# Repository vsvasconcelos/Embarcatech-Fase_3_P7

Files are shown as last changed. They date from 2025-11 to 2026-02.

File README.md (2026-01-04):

# Robô Seguidor de faixa colorida com módulo de Visão Computacional inteligente
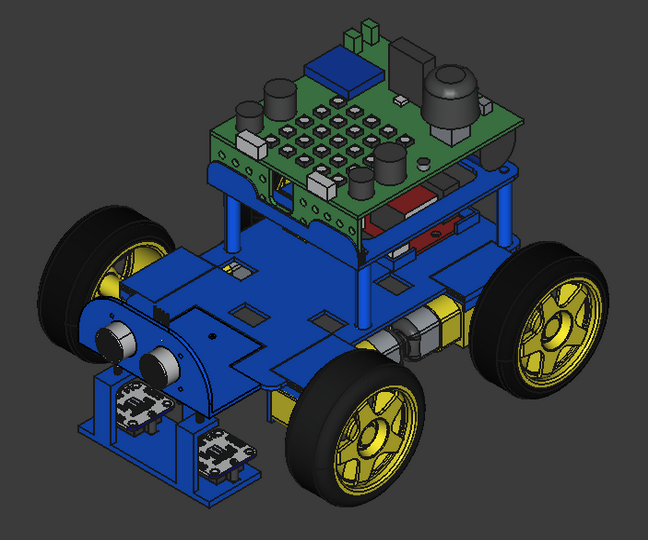
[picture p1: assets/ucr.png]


---
## Equipe:   
### Desenvolvimento: 
- [Luan Felipe Azzi](https://www.linkedin.com/in/luan-azzi/) - Robô Móvel (UCR)
- [Vagner Sanches Vasconcelos](https://www.linkedin.com/in/vsvasconcelos/) - Visão Computacional (UPV)
### Orientação:
- [Vinicius Ares](https://www.linkedin.com/in/viniciusares/)
### Coordenação:
- [Prof. Dr. Fabiano Fruett](https://www.linkedin.com/in/fabiano-fruett-816008245/)

---
## :wrench: Conteúdo   
| Pasta | Descrição |
|---|---|
| etapa_1 |Conhecendo o cliente e arquitetura do sistema |
| etapa_2 |Desenvolvimento e integração parcial dos módulos |
| etapa_3 |Testes e otimização dos sistemas |
| etapa_4 |Validação e documentação técnica final |
| etapa_5 |Entrega final |
---
## :dart: Objetivo do projeto
O objetivo geral do projeto é elevar o nível de maturidade tecnológica (TRL) de um robô móvel que, além de se locomover, será capaz de seguir diferentes cores e desviar de obstáculos no trajeto. Também é escopo um módulo de Visão Computacional inteligente que, acoplado ao robô, ampliará suas habilidades e permitirá ainda a incorporação de estratégias de controle com base em IA ao robô.

---
## Módulos   
O projeto possui dois módulos:    
- Unidade de Controle do Robô - UCR (BitDogLab - MPU Pi Pico W);     
- Unidade de Processamento de Visão - UPV (SBC - Pi Zero 2 W).     
A comunicação entre eles ocorre por meio de BLE (Bluetooth Low Energy).    
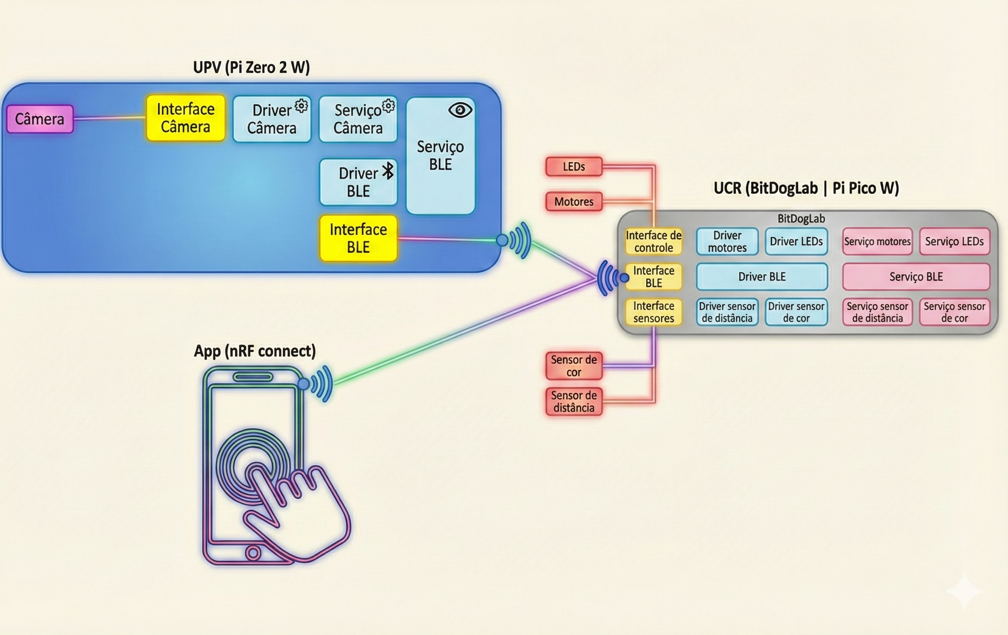
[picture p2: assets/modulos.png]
Modulos


---
### Unidade de Controle do Robô
Este projeto implementa um robô autônomo que:
- **Segue linhas coloridas** com prioridade: 🟡 Amarelo > 🔴 Vermelho > 🔵 Azul
- **Para quando detecta preto** (linha de parada)
- **Evita obstáculos** usando sensor ultrassônico
- **Indica status** através de LED RGB

#### Hardware Necessário

| Componente | Quantidade | Descrição |
|---|:---:|---|
| BitDogLab | 1 | Microcontrolador principal |
| TCS34725 | 2 | Sensor de cor I2C (esquerdo/direito) |
| SR04 (módulo I2C) | 1 | Sensor ultrassônico para obstáculos |
| BitMovel | 1 | Driver de motor |
| Motor DC | 2 | Motores para as rodas |
| LED RGB | 1 | Indicador de status |
| Botão | 1 | Start/Stop |

#### A arquitetura de software
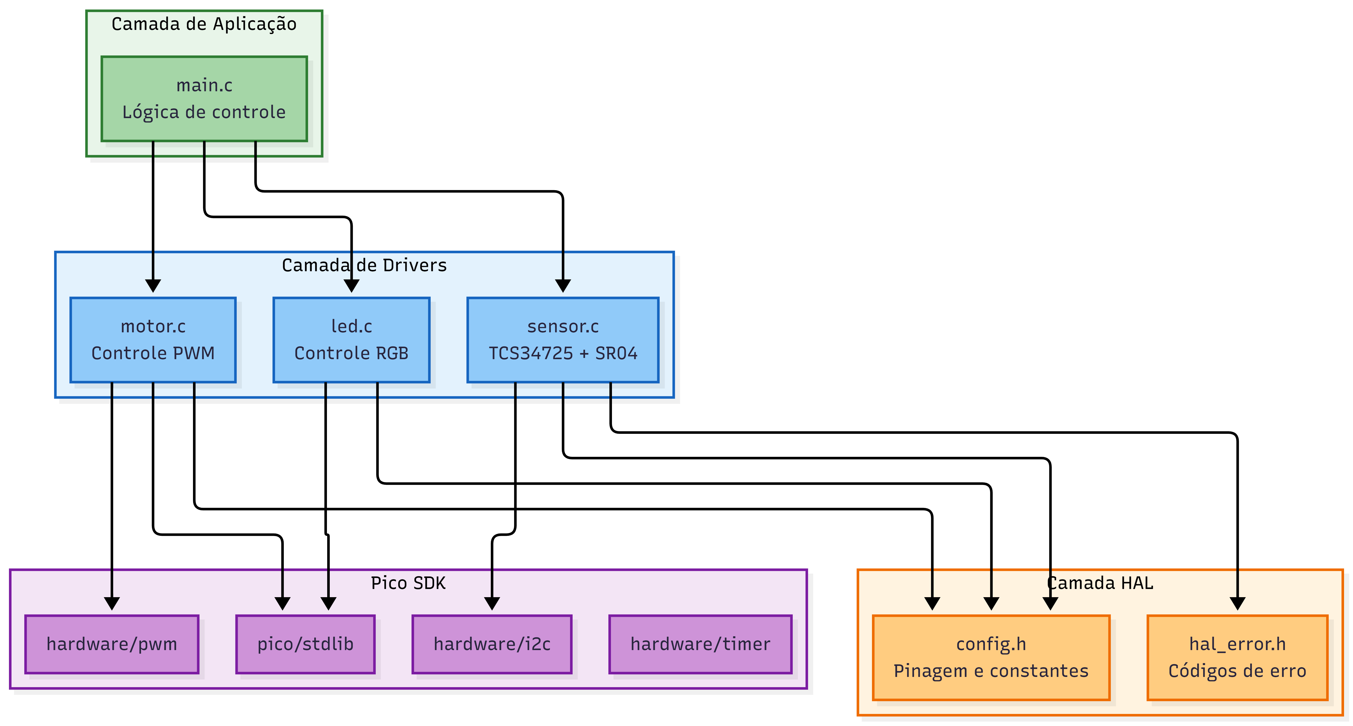
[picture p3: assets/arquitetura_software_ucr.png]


#### Fluxograma de software    
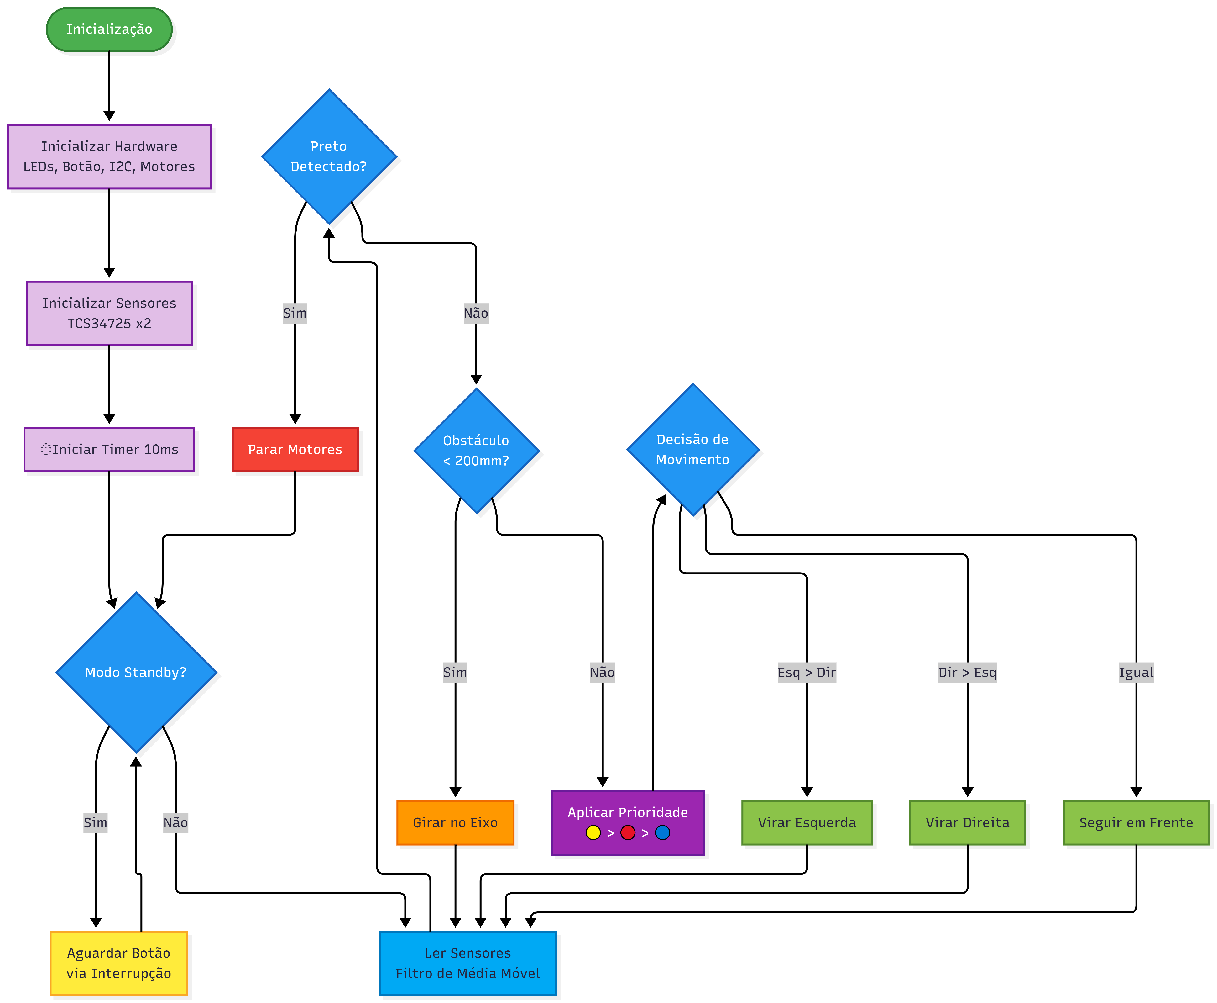
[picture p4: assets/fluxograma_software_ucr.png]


---
### Unidade de Processamento de Visão  
A UPV utiliza a SBC Pi Zero 2W com câmera de 5 MP.    
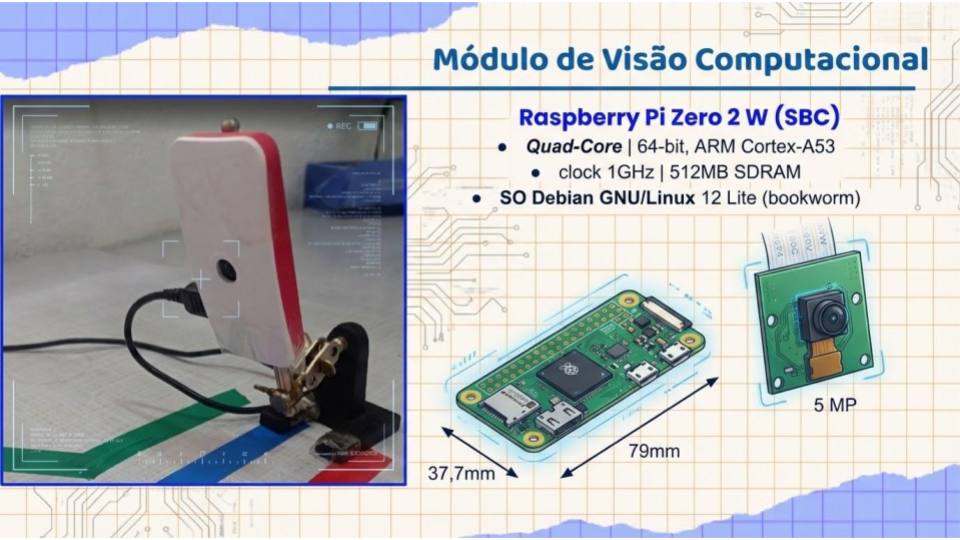
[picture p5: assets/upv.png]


#### A arquitetura de software
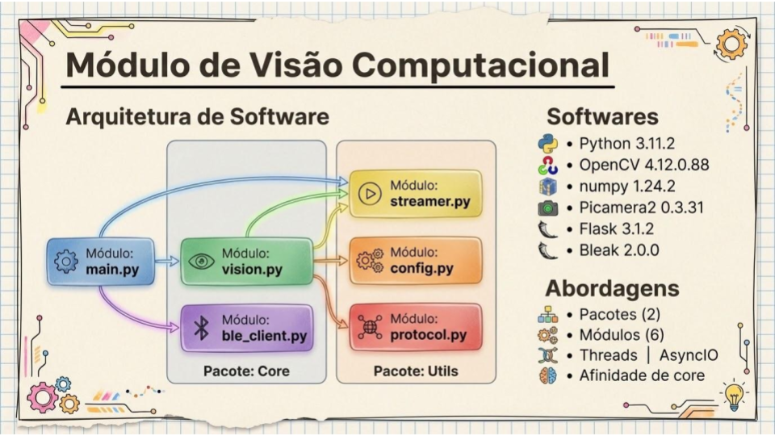
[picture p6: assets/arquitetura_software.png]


#### Diagrama de arquitetura e fluxos    
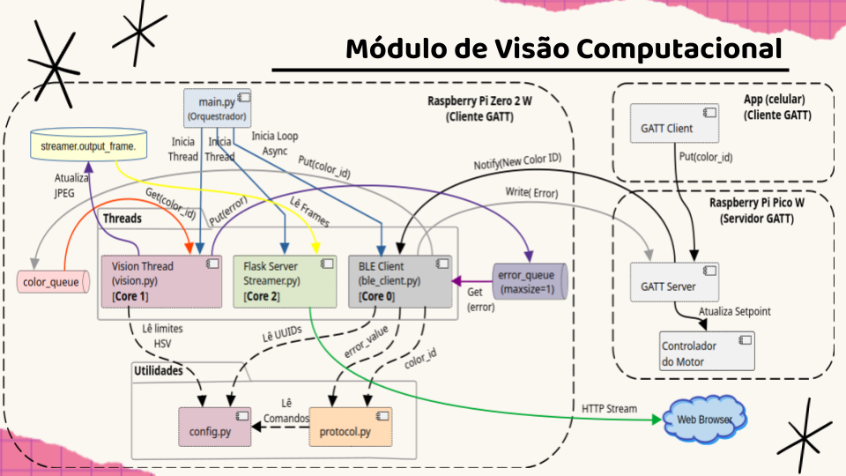
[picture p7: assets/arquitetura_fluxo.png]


## :floppy_disk: Como compilar e executar o código    
---
1. Abra o projeto no VS Code, usando o ambiente com suporte ao SDK do Raspberry Pi Pico (CMake + compilador ARM);
2. Compile o projeto normalmente (Ctrl+Shift+B no VS Code ou via terminal com cmake e make);
3. Conecte sua BitDogLab via cabo USB e coloque a Pico no modo de boot (pressione o botão BOOTSEL e conecte o cabo);
4. Copie o arquivo .uf2 gerado para a unidade de armazenamento que aparece (RPI-RP2);
5. A Pico reiniciará automaticamente e começará a executar o código.

---
## :movie_camera: Imagens e/ou vídeos do projeto em funcionamento    

### Unidade de Controle do Robô

UCR (https://youtu.be/0dy9BSEWP0k "UCR")

### Unidade de Processamento de Visão   
UPV - PiZero2W (https://youtu.be/BHwsimsb04M "UPV") 

---
## :chart_with_upwards_trend: Resultados esperados ou obtidos     

### Unidade de Controle do Robô

A UCR foi capaz de seguir as linhas coloridas individualmente (🟡 Amarelo, 🔴 Vermelho, 🔵 Azul), parar quando detectou preto (linha de parada) e evitar obstáculos usando sensor ultrassônico. O LED RGB indicava o status do robô.

---
## Referências:
-
-

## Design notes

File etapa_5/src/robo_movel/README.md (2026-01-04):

# Robô Seguidor de Linha por Cor

Projeto de robô móvel seguidor de linha que identifica e segue linhas coloridas com sistema de prioridade, desenvolvido para a **BitDogLab**.

## Descrição

Este projeto implementa um robô autônomo que:
- **Segue linhas coloridas** com prioridade: 🟡 Amarelo > 🔴 Vermelho > 🔵 Azul
- **Para quando detecta preto** (linha de parada)
- **Evita obstáculos** usando sensor ultrassônico
- **Indica status** através de LED RGB

## Hardware Necessário

| Componente | Quantidade | Descrição |
|---|:---:|---|
| BitDogLab | 1 | Microcontrolador principal |
| TCS34725 | 2 | Sensor de cor I2C (esquerdo/direito) |
| SR04 (módulo I2C) | 1 | Sensor ultrassônico para obstáculos |
| BitMovel | 1 | Driver de motor |
| Motor DC | 2 | Motores para as rodas |
| LED RGB | 1 | Indicador de status |
| Botão | 1 | Start/Stop |

## Pinagem

### I2C
| Bus | Função | SDA | SCL |
|-----|---|:---:|:---:|
| I2C0 | Sensor de cor esquerdo | GP0 | GP1 |
| I2C1 | Sensor de cor direito + Ultrassônico | GP2 | GP3 |

### Motores
| Motor | Forward | Backward | PWM |
|---|:---:|:---:|:---:|
| Esquerdo | GP9 | GP4 | GP8 |
| Direito | GP18 | GP19 | GP16 |
| Standby | GP20 | - | - |

### LED RGB
| Cor | Pino |
|-----|:----:|
| Verde | GP11 |
| Azul | GP12 |
| Vermelho | GP13 |

### Botão
- **Start/Stop**: GP5

## Como Usar

1. **Ligue o robô** - LEDs acendem indicando modo de espera
2. **Pressione o botão** (GP5) para iniciar
3. O robô começará a seguir as linhas coloridas
4. **Para parar**: coloque o robô sobre uma superfície preta

### Indicadores LED

| Cor LED | Significado |
|---|---|
| 🔴🟢🔵 (Branco) | Modo de espera |
| 🟢 Verde | Seguindo linha |
| 🔵 Azul | Evitando obstáculo |
| 🔴🔵 Magenta | Parada (preto detectado) |

## Estrutura do Projeto

```
robo_movel/
├── main.c          # Aplicação principal e lógica de controle
├── config.h        # Configurações de hardware e constantes
├── led.c/h         # Controle do LED RGB
├── motor.c/h       # Controle dos motores DC
├── sensor.c/h      # Leitura dos sensores (cor e ultrassônico)
├── CMakeLists.txt  # Configuração de build
└── README.md       # Este arquivo
```

## Configurações Ajustáveis

No arquivo `config.h`, você pode ajustar:

```c
#define MOTOR_BASE_SPEED      17000   // Velocidade base (PWM)
#define MOTOR_SPIN_SPEED      15000   // Velocidade de curva
#define MOTOR_TURN_TIME_MS    650     // Tempo de curva 90°
#define COLOR_BLACK_THRESHOLD 40      // Sensibilidade para preto
#define OBSTACLE_DISTANCE_MM  200     // Distância de obstáculo (mm)
#define COLOR_LOCK_TIME_MS    500     // Tempo de lock de prioridade
```

## Sistema de Prioridade de Cores

O robô usa um sistema inteligente para decidir qual linha seguir quando detecta múltiplas cores:

1. **Amarelo** (prioridade máxima) - Sempre seguido
2. **Vermelho** (prioridade média) - Seguido se não houver amarelo
3. **Azul** (prioridade baixa) - Seguido se não houver vermelho ou amarelo
4. **Preto** (especial) - Causa parada imediata

## Licença

Projeto desenvolvido para fins educacionais no programa **Embarcatech**.

---

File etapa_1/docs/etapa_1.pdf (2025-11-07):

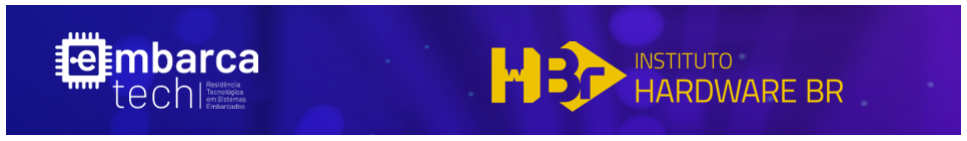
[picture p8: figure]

# Relatório de Projeto Residência Tecnológica em Sistemas Embarcados - Embarcatech

### Projeto: Robô Seguidor de Cor

Robô Seguidor de Cor com módulo de Visão Computacional inteligente

### Residentes: Luan Felipe Azzi Vagner Sanches Vasconcelos Vinícius Esperança Mantovani

### Outubro de 2025

## Histórico de Revisões

Data | Versão | Descrição
12/10/2025 | 1.0 | Semana 1 - Conhecendo o cliente e o problema
19/10/2025 | 2.0 | Semana 2 - Arquitetura e especificações
26/10/2025 | 3.0 | Semana 3 - Escolha de Hardware e Planejamento para mudanças

## Conteúdo

1 Objetivo do documento | 4
2 Conhecer o cliente e definir o problema. | 4
2.1 Canvas da proposta de valor | 4
2.2 Contexto de negócio | 7
2.3 Objetivo geral | 7
2.4 Contexto do sistema | 7
2.5 Requisitos Iniciais | 9
2.6 Avaliação do TRL atual e avanços esperados | 12
3 Arquitetura e especificações técnicas (Etapa 1 - Semana 2) | 13
3.1 Requisitos associados às camadas do sistema | 14
3.2 Diagrama de blocos | 17
3.3 Diagramas de camadas e interfaces entre módulos | 20

### 4 Escolha de Hardware e Planejamento para Mudanças (Etapa 1 - Semana 3) 21

4.1 Matriz comparativa de hardware | 21
4.2 Justificativas das escolhas | 23
4.3 Plano de abstração de hardware (HAL) | 24
4.4 Análise de Riscos | 26
4.5 Diagrama consolidado do sistema completo | 27
5 Referências | 27

# 1 Objetivo do documento

Este relatório documenta de forma sistemática todas as atividades desenvolvidas no âmbito do projeto até a data atual. Informações adicionais e novos resultados serão incorporados em versões subsequentes deste documento, conforme o progresso do trabalho.
2 Conhecer o cliente e definir o problema.

Esta seção apresenta o contexto de negócio no qual se insere o projeto 'Robô seguidor de cor com módulo de visão computacional inteligente', abrangendo seu objetivo geral, a caracterização do problema, as principais tarefas envolvidas na solução proposta, bem como os desafios e oportunidades previstos ao longo do desenvolvimento.

## 2.1 Canvas da proposta de valor

Para compreender quem é o cliente e qual problema o projeto deverá resolver, bem como identificar o valor agregado pela solução e o ambiente em que ela será utilizada, foi utilizado a ferramenta Canvas da Proposta de Valor proposta por [1] e sintetizada na Fig. 1.

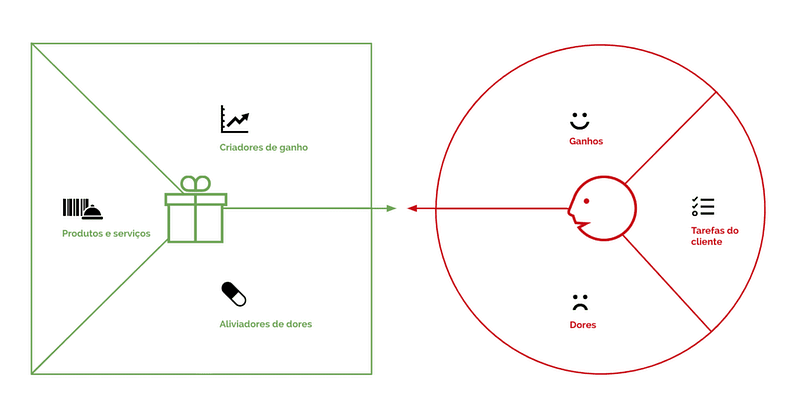
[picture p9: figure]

Figura 1 – Canvas da Proposta de Valor Fonte: [1] (https://www.zotero.org/google-docs/?iki5DS)

O Mapa do Cliente - lado direito do Canvas -, é utilizado para compreender profundamente o cliente. Seu propósito é identificar quem é o cliente, quais problemas o projeto deve resolver, o valor agregado pela solução e o ambiente em que será utilizado. Já na parte da esquerda, tem-se o Mapa de Valor, utilizado para identificar o valor agregado pela solução e o ambiente em que ela será utilizada.
Quando ambos os mapas convergem, isso é chamado de Encaixe da Proposta de Valor (Value Proposition Fit), e isso ocorre quando a proposta de valor de uma empresa atende de forma eficaz às necessidades, dores e ganhos do cliente.

### 2.1.1 Mapa do Cliente

O cenário de uso ocorre em contextos educacionais.

2.1.1.1 Tarefas do Cliente
1. Tarefas Funcionais: Capacitação de estudantes; pesquisa e desenvolvimento de estratégias de controle do robô; reputação e prestígio da instituição de ensino nas competições de robótica.
2. Tarefas Sociais: Socialização; mobilidade social.
3. Tarefas Emocionais: Aprendizagem socioemocional (soft-skills).

2.1.1.2 Dores
Investimento inicial (CAPEX) nos robôs.
1. Custos de manutenção e reposição dos robôs.
2. Falta de força de trabalho especializada em sistemas embarcados na instituição.
3. Dificuldades com o diagnóstico de falhas nos kits.
4. Falta de padronização das provas, exigindo adaptações constantes dos robôs.
5. Falta de integração curricular.
6. Trade-Off entre a gestão de resultados e o processo de aprendizagem.

2.1.1.3 Ganhos
1. Pedagógicos e de aprendizagem, com a aplicação prática de teorias abstratas como: matemática; física; programação e lógica; e o estímulo ao pensamento computacional.
2. Aprendizagem baseada em projetos (PBL).
3. Desenvolvimento da cultura maker.

4. Desenvolvimento de atitudes socioemocionais (soft skills): trabalho em equipe; colaboração; resiliência; gestão da frustração; criatividade; resolução de problemas; gestão de projetos; comunicação técnica; entre outras.
5. Ganhos de marketing e visibilidade institucional.
6. Motivação e engajamento dos alunos; capacitação e valorização dos professores; fortalecimento do sentimento de pertencimento; preparação para o mercado de trabalho.

### 2.1.2 Mapa de Valor

O protótipo do robô seguidor de cor com módulo de visão computacional inteligente será aplicável a atividades didáticas, feiras de ciência e oficinas de robótica educacional.

2.1.2.1 Aliviadores de dores
1. Robô básico com custo similar a média de mercado.
2. Robô com elevado tempo médio entre falhas (MTBF) e peças de reposição de baixo custo.
3. Sistema de diagnóstico de falhas embarcado.
4. Módulo de visão computacional (opcional), que permite adaptações automáticas para todos os tipos de provas, e ainda a implementação de novas modalidades de controle para o robô, incluindo modelos de inteligência artificial.

2.1.2.2 Criadores de ganhos
1. Robô programável, em linguagens de alto nível e Low/No-Code, permitindo a aplicação prática de: matemática; física; programação e lógica, bem como, a aplicação de IA, com o módulo opcional de visão computacional.
2. Aplicação plena da abordagem pedagógica do PBL e da cultura maker.
3. Desenvolvimento amplo de capacidades multidisciplinares de hard e soft-skill.
4. Aumento das chances de ganhos de marketing e visibilidade institucional, principalmente com o robô embarcado com visão computacional.

5. Preparação dos alunos para o mercado de trabalho e para a vida (soft-skill).

2.1.2.3 Produtos e serviços
1. Robô móvel, sem fio e com 4 rodas, capaz de seguir faixas de cores e desviar de obstáculos de forma autônoma. Em sua versão básica, as habilidades de seguir a faixa e desviar de obstáculos ocorrem por meio de sensores de cor e distância (TOF/Ultrassônico).
2. Módulo opcional de visão computacional, que amplia as habilidades do robô, habilitando-o para competições em trilhas mais desafiadoras. Este módulo é acoplado facilmente a versão básica do robô, e também permite a incorporação de novas estratégias de controle, inclusive com técnicas de Inteligência Artificial.

## 2.2 Contexto de negócio

O mercado de robótica educacional no Brasil vive um momento de expansão acelerada, impulsionado principalmente pela implementação da Base Nacional Comum Curricular (BNCC), que incorporou o pensamento computacional como competência obrigatória, e ainda pela crescente conscientização sobre a importância das habilidades STEM (Ciência, Tecnologia, Engenharia e Matemática). Este marco regulatório abriu um mercado potencial de milhões de estudantes nas redes pública e privada.
Conforme [2], esse mercado terá um crescimento exponencial, chegando a US$135 milhões até 2035, o que representa um crescimento de 300% em relação a 2023.

## 2.3 Objetivo geral

O objetivo geral do projeto é elevar o nível de maturidade tecnológica (TRL) de um robô móvel que, além de se locomover, será capaz de seguir diferentes cores e desviar de obstáculos no trajeto. Também é escopo um módulo de Visão Computacional inteligente que, acoplado ao robô, ampliará suas habilidades e permitirá ainda a incorporação de estratégias de controle com base em IA ao robô.

## 2.4 Contexto do sistema

A seguir, é apresentado um diagrama de contexto do sistema. Por meio dele, é possível identificar as interações do robô com os fatores externos que atuam sobre seu funcionamento. Nesse diagrama, pode-se notar a relação do robô com obstáculos, que o fazem parar e aguardar até sua retirada, a relação com uma faixa de cor específica, a qual ele deve seguir e, a relação com o usuário, que determina o destino do robô (determinando, por consequência a cor a ser seguida) e recebe confirmações e outras informações do robô.

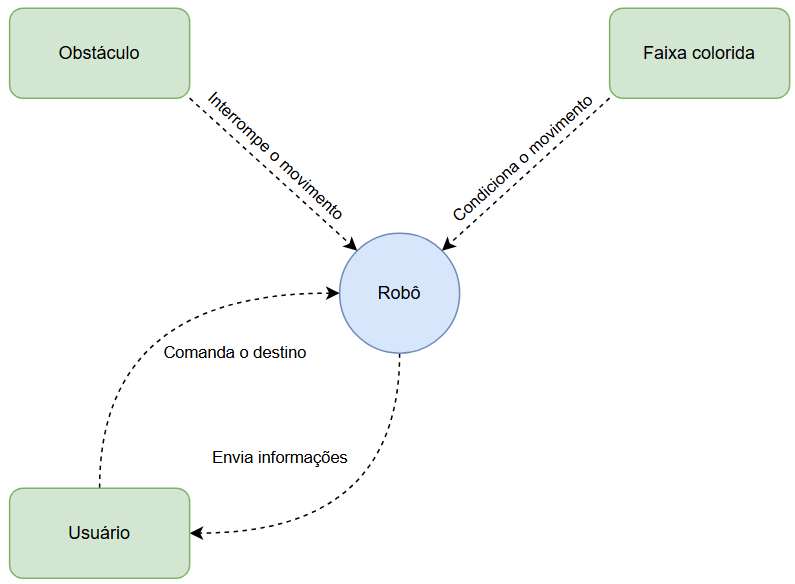
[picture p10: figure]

Figura 2 – Diagrama de Contexto do Sistema

Adicionalmente, tem-se um segundo diagrama, explicando as relações do Robô com fatores externos no caso de uso do módulo de visão computacional opcional. Nesse caso, o robô recebe comandos de controle do módulo, como forma de aumentar a precisão de seus movimentos majoritariamente na função de seguir cor.

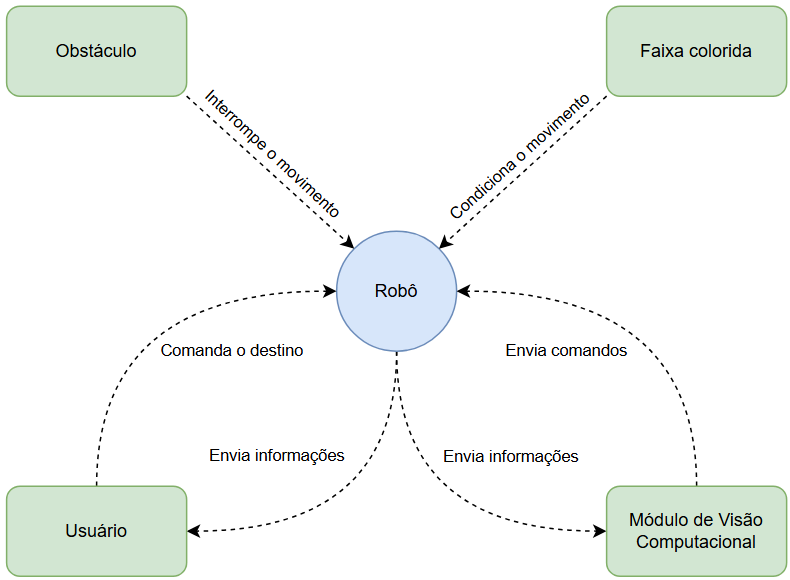
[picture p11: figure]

Figura 3 – Diagrama de Contexto do Sistema com Módulo de Visão Computacional

## 2.5 Requisitos Iniciais

A seguir, encontra-se a tabela de requisitos iniciais a ser seguida para o desenvolvimento do projeto.

ID | Tipo | Descrição breve | Prior | Critério de Aceitação
FR - 01 | Func | Movimentar-se | 1 | O robô é capaz de se mover para frente e para trás em linha reta, fazer curvas e girar para ambos os lados
FR - 02 | Func | Seguir linha | 2 | O robô é capaz de seguir uma linha
FR - 03 | Func | Distinguir linhas de diferentes cores | 3 | O robô distingue a cor de diferentes linhas e segue aquela de cor correta
FR - 04 | Func | Interromper o movimento na presença de obstáculo | 2 | O robô interrompe seu movimento caso exista um obstáculo em seu caminho, até que esse seja retirado
FR - 05 | Func | Aceitar comandos de destino remotos | 4 | O robô recebe e interpreta comandos remotos indicando a cor a ser seguida e a segue
FR - 06 | Func | Buscar a linha | 4 | Caso se perca da linha que

| | perdida | | seguia, o robô procura reencontrá-la. Caso a encontre, segue no primeiro sentido que encontrar. Caso contrário, fica parado
FR - 07 | Func | Executar comandos do módulo de visão computacional | 5 | Caso um módulo de visão seja detectado, o robô se torna um receptor de comandos, que atua sob demandas da Micro Processing Unity (MPU) controladora do sistema de visão
FR-08 | Func | Otimização de Energia | 1 | Otimização do consumo de energia para operação contínua do robô
FR-09 | Func | Adaptação do chassi existente | 5 | Caso necessário, adaptar e chassi de 4 rodas existente para melhorar a performance do robô
FR-10 | Func | Módulo de visão computacional

1
Sistema opcional à versão básica do robô, capaz de ampliar as suas capacidades originais de seguir faixas e desviar de obstáculos, permitindo
adaptações automáticas para todos os tipos de provas, e ainda a implementação de novas
modalidades de controle para o robô.

Deve ser implementado em outro microcontrolador (MPU) e
interagir com a BitDogLab para que esta realize o controle dos movimentos do robô.

Pode utilizar visão computacional clássica e/ou moderna (redes neurais).

| | | | Deve possuir dimensões físicas que não impactem substancialmente a performance do chassi atual do robô.
NFR - 01 | Não Func | Movimentar-se | 1 | O robô usa seus atuadores para movimentar suas rodas de modo a garantir que ele possa seguir em linha reta, fazer curvas e girar no próprio eixo
NFR - 02 | Não Func | Detectar uma linha e seguí-la | 2 | O robô usa seus sensores de cor para detectar a existência da linha de cor diferente da cor de fundo (branca branca por padrão) e segue por ela, verificando periódicamente para que direção deve seguir para acompanhá-la
NFR - 03 | Não Func | Escolher qual cor deve seguir | 3 | O robô verifica a presença de linha de cor específica por meio de seus sensores de cor e, caso a encontre, segue em sua direção.
NFR - 04 | Não Func | Interromper o movimento no caso de detectar uma superfície a sua frente | 2 | O robô detecta um obstáculo utilizando um sensor ultrassônico que o envia informações e distância periódicamente. No momento em que a distância for menor que um threshold determinado, o robô para de se mover até detectar um aumento dessa distância
NFR - 05 | Não Func | Receber e atender a comandos de destino remotos (via bluetooth, wifi ou outro meio de comunicação) | 4 | O robô recebe um comando que o indica a cor a ser seguida, processa esse comando e busca por essa cor entre os dados atuais de seus sensores de cor. Caso a encontre, envia uma confirmação para o aparelho controlador e segue na direção da linha de cor comandada
NFR - 06 | Não Func | Buscar pela linha perdida girando em seu eixo | 4 | Ao identificar que em nenhum de seus sensores a cor que seguia é detectada, o robô gira em seu próprio eixo até encontrá-la em um de seus sensores e, caso a

| | | | encontre, segue no sentido em que a encontrou. Caso contrário, mantém-se parado até intervenção externa
NFR - 07 | Não Func | Executar comandos do módulo de visão computacional | 5 | Quando em conexão com um módulo de visão computacional, o robô atua como um receptor de comandos e condiciona seu movimento ao controle da MPU controladora. Podendo ignorar os demais sensores que possui ou tratá-los em conjunto com as informações advindas da MPU
NFR - 08 | Não Func | Custo | 1 | Robô básico com custo similar a média de mercado e peças de reposição de baixo custo
NFR - 09 | Não Func | Robustez | 1 | Robô com elevado tempo médio entre falhas (MTBF)

Tabela 1 – Requisitos Funcionais e Não Funcionais do robô Fonte:

## 2.6 Avaliação do TRL atual e avanços esperados

Atualmente, já escolhemos os componentes e conhecemos os requisitos iniciais, tendo também a plataforma base pronta (chassi de 4 rodas radiocontrolado), conforme figura 4. No entanto, a integração dos sensores de distância e cor e da câmera para realizar uma navegação autônoma existe apenas conceitualmente, sem uma prova da viabilidade prática. Por isso, avalia-se o TRL atual como 2 - Conceito da tecnologia formulado.
Espera-se que, ao fim do período estipulado para realização do projeto, o TRL seja 4 - Validação de componente e arranjo em ambiente de laboratório, posto que temos como principal objetivo ter um protótipo funcional que execute bem as tarefas de seguir cor e desviar de obstáculos em um circuito de testes em salas de aula e feiras de ciência. Para isso, o primeiro passo é ter uma Prova de Conceito (TRL 3), integrando os sensores ao chassi e desenvolvendo um código inicial que prove que é possível ler os dados de cor e distância e, a partir disso, controlar o carrinho.

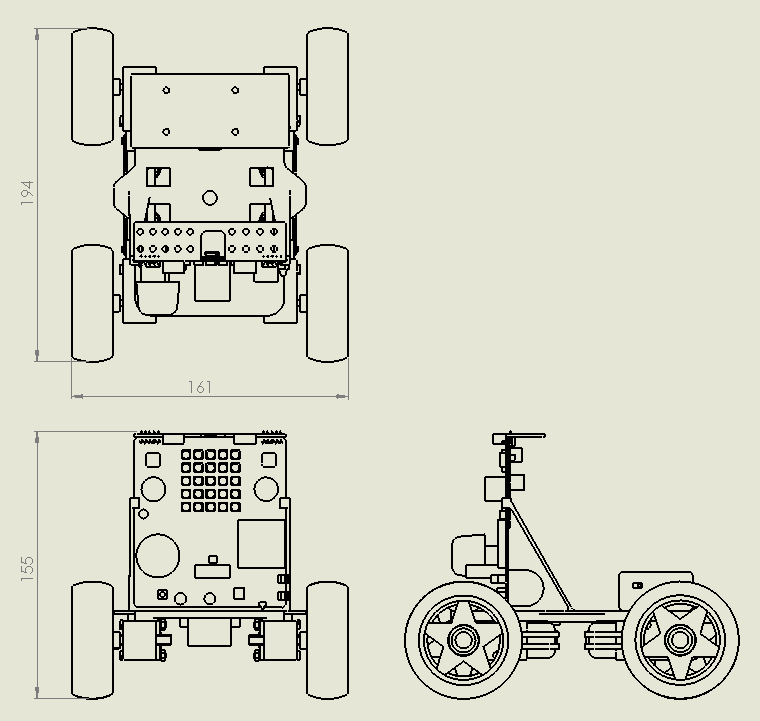
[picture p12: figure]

Figura 4 – Robô Móvel Skid-Steer fornecido. Fonte: Produzido pelos autores.

Finalmente, para alcançar o TRL 4, deve-se refinar o protótipo construído. Para tanto, é preciso desenvolver uma estrutura final e realizar testes em diversos cenários para garantir que sua confiabilidade e desempenho estão de acordo com o que foi definido nos requisitos. Assim, teremos um produto mínimo viável com garantia de funcionamento atestada em laboratório.
Todos os desenhos para impressão 3D do chassis também foram fornecidos, por meio de um diretório compartilhado, (https://docs.google.com/document/d/1av3HyENQ0uDQUAegyIoF8aRYq_Q_j9dXiuD2IEWV4Wc/edit?tab=t.0) bem como a versão atual do firmware (https://github.com/BitDogLab/BitDogLab/tree/main/softwares/RoboMovel) do robô, na linguagem MicroPython, abaixo tem-se a lista de materiais utilizados no robô fornecido:
- 01 Placa BitDogLab v7;
- 04 motores tt dc 3-6V com redutor e roda de 68mm;
- 02 motores traseiros (master) com rabichos JST-SH 2P e 4 jumpers fêmea soldados;
- 02 motores dianteiros (slave) com 4 jumpers macho soldados;
- 01 chassis impresso em ABS v4;
- 02 mãos-francesas impressas em ABS v3;
- 04 parafusos M3x25;
- 04 porcas M3;
- 01 módulo ponteH tbn6612fng (módulo em PCB BitDogLab);

- 01 cabo flat IDC 02x07;
- 01 suporte para 2 baterias 18650;
- 02 baterias Li-Ion 3,7V 18650;
- 01 conector XT30 macho;
- 01 módulo bluetooth HC05;
- fita dupla-face, para colar as mãos francesas no chassis.
Para controlar o robô pelo celular, foram utilizados os aplicativos:
- Arduino Bluetooth Controller (por Giristudio);
- BT Car Controller-Arduino/ESP (por Giristudio).

# 3 Arquitetura e especificações técnicas (Etapa 1 - Semana 2)

Esta seção apresenta as especificações técnicas do robô em função das necessidades levantadas, bem como a estruturação da arquitetura do sistema, garantindo clareza e modularidade, e ainda relaciona os requisitos às camadas do modelo de sistema embarcado, envolvendo: sensores/atuadores; conectividade; processamento local; armazenamento; abstração; e interface.

## 3.1 Requisitos associados às camadas do sistema

A tabela 2 apresenta o refinamento dos requisitos levantados na semana 1 associados às camadas do sistema.

ID | Tipo | Descrição breve | Prior | Critério de Aceitação | Camada
FR - 01 | Func | Movimentar-se | 1 | O robô é capaz de se mover para frente e para trás em linha reta, fazer curvas e girar para ambos os lados | Atuador
FR - 02 | Func | Seguir linha | 2 | O robô é capaz de seguir uma linha | Processamento local/Sistema de Controle
FR - 03 | Func | Distinguir linhas de diferentes cores | 3 | O robô distingue a cor de diferentes linhas e segue aquela de cor correta | Sensor de cor
FR - 04 | Func | Interromper o movimento na | 2 | O robô interrompe seu movimento caso exista um | Sensor de Colisão

| | presença de obstáculo | | obstáculo em seu caminho, até que esse seja retirado
FR - 05 | Func | Aceitar comandos de destino remotos | 4 | O robô recebe e interpreta comandos remotos indicando a cor a ser seguida e a segue | Conectividade Processamento local/Sistema de Controle
FR - 06 | Func | Buscar a linha perdida | 4 | Caso se perca da linha que seguia, o robô procura reencontrá-la. Caso a encontre, segue no primeiro sentido que encontrar. Caso contrário, fica parado | Processamento local/Sistema de Controle
FR - 07 | Func | Executar comandos do módulo de visão computacional | 5 | Caso um módulo de visão seja detectado, o robô se torna um receptor de comandos, que atua sob demandas da Micro Processing Unity (MPU) controladora do sistema de visão | Conectividade Processamento local/Sistema de Controle Interface
FR-08 | Func | Otimização de Energia | 1 | Otimização do consumo de energia para operação contínua do robô | Processamento local/Sistema de Controle
FR-09 | Func | Adaptação do chassi existente | 5 | Caso necessário, adaptar e chassi de 4 rodas existente para melhorar a performance do robô | Interface
FR-10 | Func | Módulo de visão computacional | 1 | Sistema opcional à versão básica do robô, capaz de ampliar as suas capacidades originais de seguir faixas e desviar de obstáculos, permitindo adaptações automáticas para todos os tipos de provas, e ainda a implementação de novas modalidades de controle para o robô. Deve ser implementado em outro microcontrolador (MPU) e interagir com a BitDogLab | Conectividade Processamento local/Sistema de Controle Interface

| | | | para que esta realize o controle dos movimentos do robô. Pode utilizar visão computacional clássica e/ou moderna (redes neurais). Deve possuir dimensões físicas que não impactem substancialmente a performance do chassi atual do robô.
NFR - 01 | Não Func | Movimentar-se | 1 | O robô usa seus atuadores para movimentar suas rodas de modo a garantir que ele possa seguir em linha reta, fazer curvas e girar no próprio eixo | Atuador
NFR -02 | Não Func | Detectar uma linha e seguí-la | 2 | O robô usa seus sensores de cor para detectar a existência da linha de cor diferente da cor de fundo (branca branca por padrão) e segue por ela, verificando periódicamente para que direção deve seguir para acompanhá-la | Sensores
NFR -03 | Não Func | Escolher qual cor deve seguir | 3 | O robô verifica a presença de linha de cor específica por meio de seus sensores de cor e, caso a encontre, segue em sua direção. | Sensores Processamento local/Sistema de Controle
NFR -04 | Não Func | Interromper o movimento no caso de detectar uma superfície a sua frente | 2 | O robô detecta um obstáculo utilizando um sensor ultrassônico que o envia informações e distância periódicamente. No momento em que a distância for menor que um threshold determinado, o robô para de se mover até detectar um aumento dessa distância | Sensores Processamento local/Sistema de Controle
NFR -05 | Não Func | Receber e atender a comandos de destino remotos (via bluetooth, wifi ou outro | 4 | O robô recebe um comando que o indica a cor a ser seguida, processa esse comando e busca por essa cor entre os dados atuais de seus sensores de cor. Caso a | Sensores Conectividade Processamento local/Sistema de Controle

| | meio de comunicação) | | encontre, envia uma confirmação para o aparelho controlador e segue na direção da linha de cor comandada
NFR -06 | Não Func | Buscar pela linha perdida girando em seu eixo | 4 | Ao identificar que em nenhum de seus sensores a cor que seguia é detectada, o robô gira em seu próprio eixo até encontrá-la em um de seus sensores e, caso a encontre, segue no sentido em que a encontrou. Caso contrário, mantém-se parado até intervenção externa | Sensores Processamento local/Sistema de Controle
NFR -07 | Não Func | Executar comandos do módulo de visão computacional | 5 | Quando em conexão com um módulo de visão computacional, o robô atua como um receptor de comandos e condiciona seu movimento ao controle da MPU controladora. Podendo ignorar os demais sensores que possui ou tratá-los em conjunto com as informações advindas da MPU | Conectividade Processamento local/Sistema de Controle Interface
NFR -08 | Não Func | Custo | 1 | Robô básico com custo similar a média de mercado e peças de reposição de baixo custo | N/A
NFR -09 | Não Func | Robustez | 1 | Robô com elevado tempo médio entre falhas (MTBF) | N/A
NFR -10 | Não Func | Trilhas lúdicas | 1 | Poster com trilhas lúdicas para aplicação de atividades com o robô móvel | N/A

Tabela 2 – Requisitos associados às camadas

## 3.2 Diagrama de blocos

Em sequência, são apresentados os diagramas de blocos dos principais componentes do robô, os quais foram elaborados mediante a aplicação de princípios de modularidade e de padrões de projeto consagrados, visando à clareza e à eficiência da arquitetura proposta.

### 3.2.1 Hardware

Seguem abaixo os diagramas de blocos dos módulos do robô móvel, que funciona independente de qualquer acessório, e do sistema de visão computacional, que será um opcional, mas estenderá sobremaneira as capacidades do robô.

3.2.1.1 Robô Móvel
Na Figura 5 abaixo, tem-se um diagrama de blocos do hardware do robô a ser desenvolvido. Nesse diagrama, pode-se notar a diferença de cores entre conjuntos de blocos:
- Amarelo: Bateria, componente essencial para alimentação da MCU, da Ponte H e dos motores;
- Verde: Ponte H e Motores, blocos compostos, o primeiro pela ponte h tbn6612fng do robô e o segundo pelos motores traseiros e dianteiros. Este é o conjunto atuador, responsável por induzir a movimentação do robô;
- Roxo: Módulo Bluetooth, periférico responsável pela comunicação bluetooth com o controlador remoto (smartphone);
- Azul: Raspberry Pi Pico W, cérebro do robô, MCU que recebe dados dos sensores e envia dados aos atuadores, responsável pelo controle do robô e aquisição de informações relevantes;
- Vermelho: Sensores de Distância e Sensores de Cor, componente responsável pelo sensoriamento do robô. O primeiro bloco se refere aos sensores de distância do robô, utilizados para a detecção de obstáculos e, o segundo, refere-se aos sensores de cor do robô, utilizados para guiar o robô na direção da linha de cor desejada.

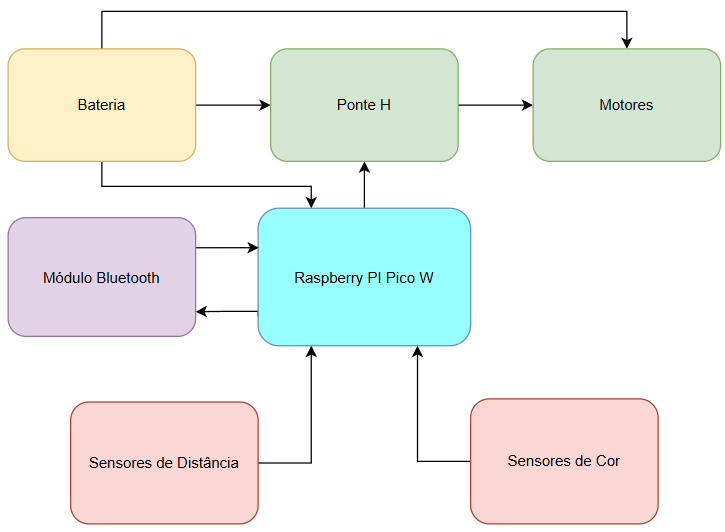
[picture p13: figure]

Figura 5 - Diagrama de Blocos de Hardware do Robô Fonte: Produzido pelos Autores.
3.2.1.2 Sistema de Visão
A Figura 6 apresenta as entradas/saídas do módulo de visão computacional.

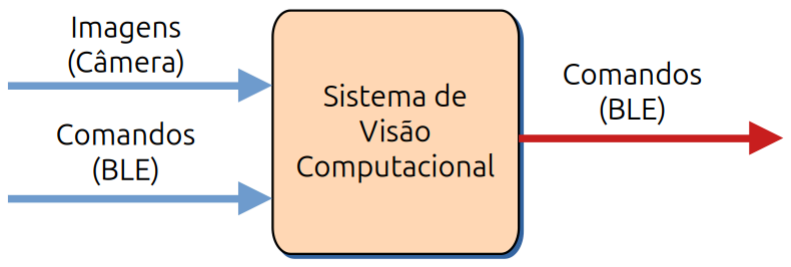
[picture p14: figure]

Figura 6– Módulo de Visão Computacional Fonte: Produzido pelos Autores.
Conforme apresentado na Figura 7, existem vários hardwares no mercado que, em tese, poderiam atender a aplicação escopo deste projeto.

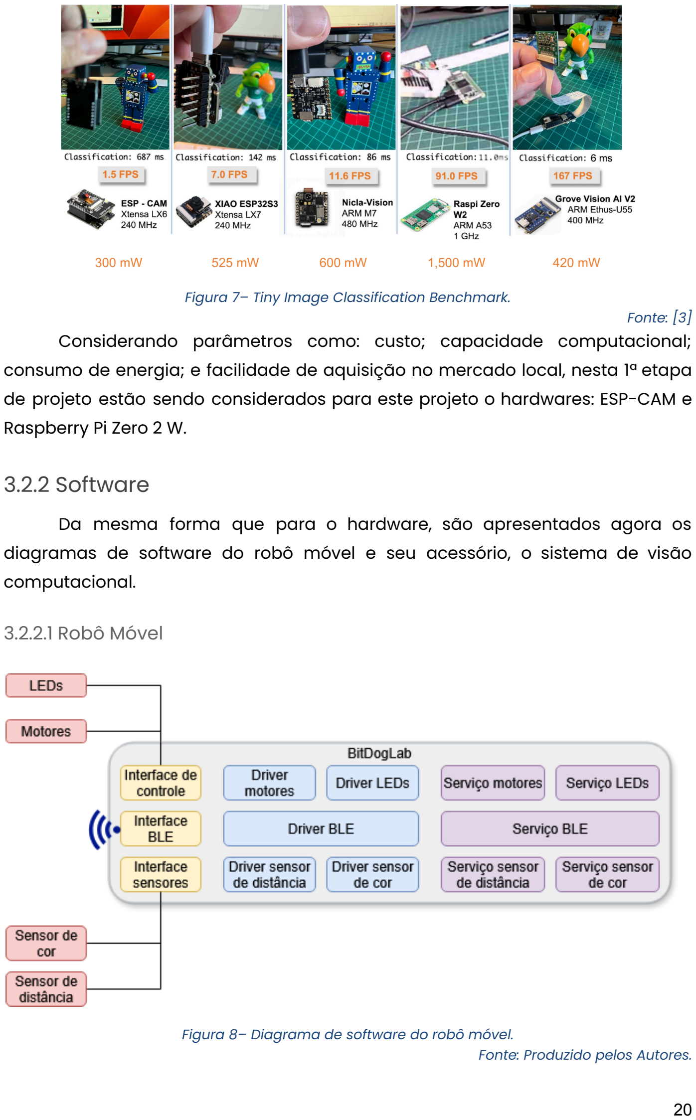
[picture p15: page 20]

Figura 7– Tiny Image Classification Benchmark. Fonte: [3]
Considerando parâmetros como: custo; capacidade computacional; consumo de energia; e facilidade de aquisição no mercado local, nesta 1ª etapa de projeto estão sendo considerados para este projeto o hardwares: ESP-CAM e Raspberry Pi Zero 2 W.

### 3.2.2 Software

Da mesma forma que para o hardware, são apresentados agora os diagramas de software do robô móvel e seu acessório, o sistema de visão computacional.

3.2.2.1 Robô Móvel

Figura 8– Diagrama de software do robô móvel. Fonte: Produzido pelos Autores.

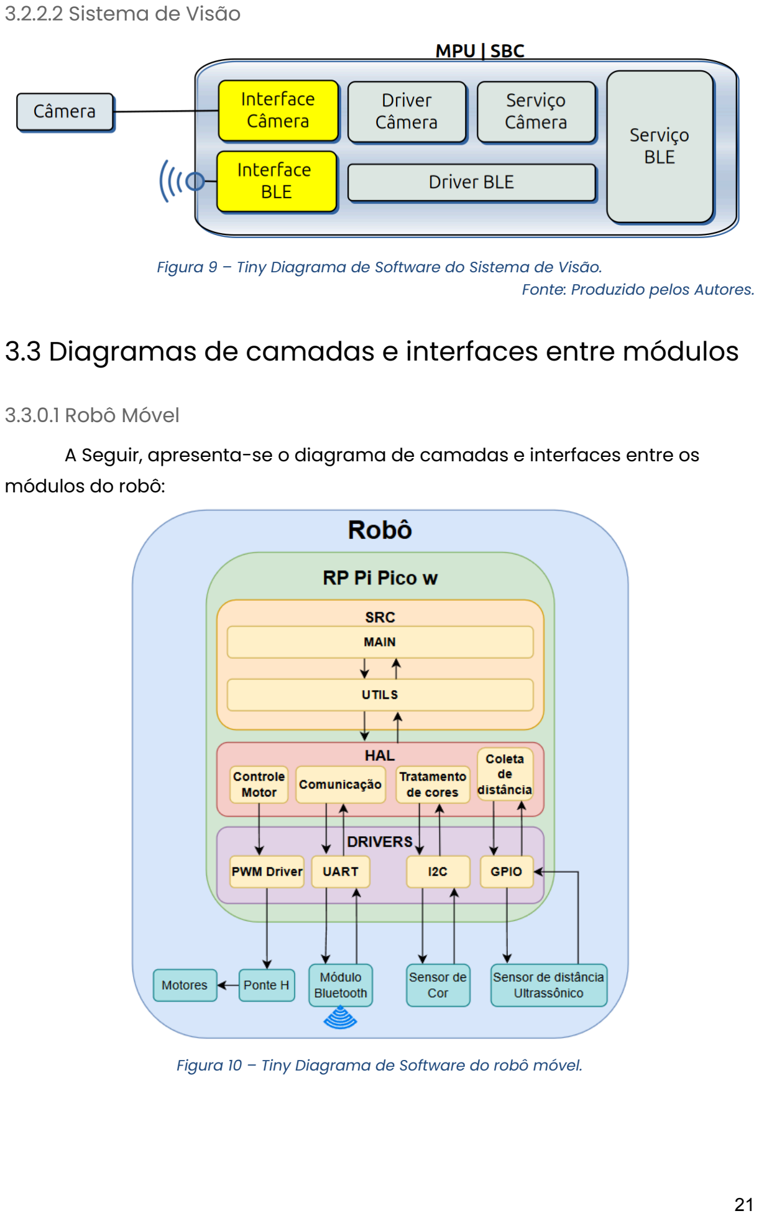
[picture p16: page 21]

3.2.2.2 Sistema de Visão

Figura 9 – Tiny Diagrama de Software do Sistema de Visão. Fonte: Produzido pelos Autores.

## 3.3 Diagramas de camadas e interfaces entre módulos

3.3.0.1 Robô Móvel
A Seguir, apresenta-se o diagrama de camadas e interfaces entre os módulos do robô:

Figura 10 – Tiny Diagrama de Software do robô móvel.

3.3.0.2 Sistema de Visão

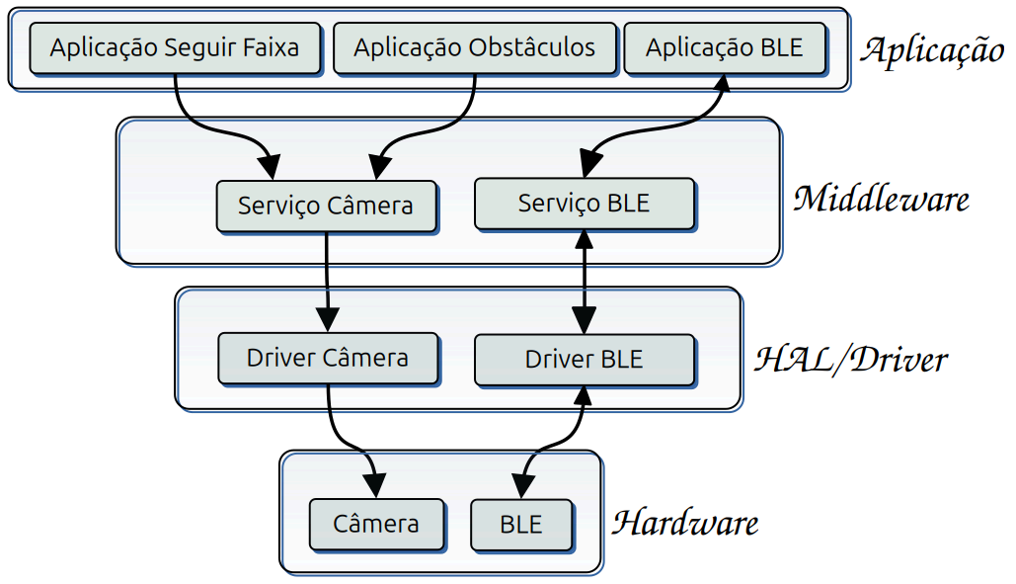
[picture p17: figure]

Figura 11 – Diagrama de camadas do Sistema de Visão. Fonte: Produzido pelos Autores.

# 4 Escolha de Hardware e Planejamento para Mudanças (Etapa 1 - Semana 3)

Os objetivos desta etapa são:
- Selecionar o hardware e tecnologias coerentes com as especificações do sistema;
- Planejar a resiliência a mudanças de componentes ou tecnologias; e
- Documentar as justificativas técnicas das escolhas realizadas.

## 4.1 Matriz comparativa de hardware

Nesta seção serão comparados: microcontroladores; SBC

1
; sensores;
módulos de rede; fontes de alimentação; entre outros.

1 SBC: Single Board Computer (Computador de Placa Única).

### 4.1.1 Robô móvel

A tabela 4 apresenta a matriz comparativa de hardwares candidatos a atender o módulo do robô móvel, escopo deste projeto.

| Opção A | Opção B | Opção C | Critério
MCU / Placa | BitDogLab V7 (RP2040 / Pico W) | BitDogLab V6 (RP2040 / Pico W) | - | Integração com kit, disponibilidade de GPIO, custo
Sensor de cor | TCS34725 | TCS3200 | TCRT5000 | Precisão na leitura de cor e facilidade I²C
Sensor de distância | VL53L1X (TOF) | HC-SR04 | - | Precisão e imunidade a superfície/tipo de solo
Comunicação Externa | HC-05 | Wi-Fi | BLE | Facilidade de uso para controle manual e integração
Ponte H | TBN6612FN G | L298N | - | Corrente, eficiência, montagem
Motores | 4× TT 3–6V | - | - | Eficiência, velocidade
Alimentação | Bateria 18650 3.7V | - - | | Tensão compatível, autonomia, segurança
Facilidade de Aquisição | Fácil | Médio | Fácil | Facilidade em comprar os itens
Custo aproximado (R$) | 300 a 500 | | | -

Tabela 4 – Matriz comparativa de hardware para robô móvel. Fonte: Produzido pelos Autores.

### 4.1.2 Sistema de Visão

A tabela 5 apresenta a matriz comparativa de hardwares candidatos a atender o módulo de visão computacional, escopo deste projeto.

| ESP32-CAM | XIAO ESP32S3 | Nicla-Vision | Raspberry Pi Zero 2 W | Grove Vision AI V2
Processador | Dual-Core Tensilica LX6 240 MHz (ESP32-S) | Dual-Core LX7 240 MHz (ESP32-S3) | ARM Cortex-M7 480 MHz (STM32H74 7AII6) | SBC ARM Quad-Core 64-bit Cortex-A53 1 GHz (Pi RP3A0) | ARM Cortex-M55 (HX6538 ASIC 2 de IA Ethus-U55)
Bluetooth | 4.2 (BLE) | 5.0 (BLE) | 4.2 (BLE) | 4.2 (BLE) | Não Possui
Tempo Classificação 3 | 687 ms | 142 ms | 86 ms | 11 ms | 6 ms
FPS 4 | 1.5 | 7.0 | 11.6 | 91.0 | 167
Potência [W] | 300 mW | 525 mW | 600 mW | 1500 mW | 420 mW
Tensão de Alimentação | 5 V e 3.3 V | 5 V e 3.7 V | 5 V e 3.7 V | 5 V | 5 V e 3.3 V
Tensão dos GPIO (Operação) | 3.3 V | 3.3 V | 3.3 V | 3.3 V | 3.3 V
Custo [R$] | 90,00 | 240,00 | 1.250,00 | 400,00 | 350,00
Facilidade de Aquisição | Muito Fácil | Difícil | Fácil | Muito Fácil | Difícil

Tabela 5 – Matriz comparativa de hardware para módulo de visão.
Fonte: Produzido pelos Autores.
Considerando as características, os dois hardwares candidatos a atender o módulo de visão computacional são: ESP32-CAM e Raspberry Pi Zero 2 W.

## 4.2 Justificativas das escolhas

Nesta seção, todas as escolhas serão justificadas de forma técnica e econômica.

4 FPS: Quadros por Segundo, número de imagens que uma câmera captura e exibe a cada segundo.

3 Tempo de Classificação: Tempo que o hardware demora para fazer a inferência em um modelo de classificação de imagens.

2 ASIC: Circuito integrado de aplicação específica, neste caso, aplicações de IA.

### 4.2.1 Robô móvel

Microcontrolador: A escolha é justificada pela necessidade do uso da BitDogLab no projeto. As características, como o processador dual-core, e principalmente, o suporte oficial a MicroPython, alinham-se perfeitamente com os objetivos do projeto.
Sensor de Distância: Para a prova de conceito e validação em laboratório, o HC-SR04 é a melhor escolha, dado que seu custo extremamente baixo cumpre o requisito de manter o robô básico com um custo similar à média de mercado. Tecnicamente, seu alcance e precisão são suficientes para a detecção de obstáculos em ambientes controlados. Já o VL53L1X é robusto para detecção de obstáculos em superfícies diversas, podendo ser usado como fallback.
Sensor de Cor (TCS34725): Apesar de um custo superior ao TCS3200, o TCS34725 é a escolha técnica superior, dado que sua interface I2C economiza pinos GPIO no Pico W e simplifica o hardware. A leitura direta de valores RGB, juntamente com o filtro de IR, oferece maior precisão na distinção de cores sob diferentes condições de iluminação, o que é fundamental para o requisito FR-03. Em último caso, há o TCRT5000 que é apenas um sensor infravermelho para linhas pretas e brancas, sendo muito confiável e utilizado em seguidores de linha.

### 4.2.2 Sistema de Visão

De todas as alternativas apresentadas na tabela 4, os dois hardwares candidatos a atender o módulo de visão computacional são: ESP32-CAM e Raspberry Pi Zero 2 W.
Exceto pela dificuldade de aquisição no mercado local, o Grove Vision AI V2 seria a melhor opção para este caso de uso, uma vez que, por um bom preço, consegue entregar uma excepcional capacidade computacional, consumindo relativamente pouca potência elétrica; contudo, esse hardware não possui bluetooth, que é um requisito para o módulo de visão. Importante destacar aqui que esse hardware não é um microcontrolador ou uma SBC, ele é um módulo acelerador de IA, também conhecido como co-processador de visão. Sua principal função é ser um "periférico inteligente" que deve se conectar a outra placa (host), como a BitDogLab por exemplo, dando a ela "superpoderes" de visão computacional, com consumo de energia baixíssimo.
A Nicla-Vision tem um preço alto pelo desempenho que entrega.
O XIAO ESP32S3, assim como o Grove Vision AI V2, apresenta dificuldades de aquisição no mercado local.

Desta forma, as melhores alternativas de hardware são: ESP32-CAM e Raspberry Pi Zero 2 W.
A ESP32-CAM é a opção mais barata, contudo, possui baixíssima poder computacional, comparado às outras alternativas, assim, um ponto de atenção para utilizá-la, em projetos de visão computacional, será a escolha de bibliotecas/frameworks que requerem menos capacidade computacional.
A Raspberry Pi Zero 2 W apresenta boa capacidade computacional, permitindo a utilização de bibliotecas/frameworks mais sofisticados de visão computacional, contudo, um ponto de atenção é sua tensão de alimentação de 5V. Assim, para utilizá-lo, será necessário elevar a tensão das baterias e regulá-la, o que pode ser realizado com módulos do tipo: Módulo Carregador Duplo USB 5V 2A para Bateria 18650 - Modelo: JX-887Y. (https://www.mamuteeletronica.com.br/modulo-carregador-duplo-usb-5v-2a-para-bateria-18650-20201)

## 4.3 Plano de abstração de hardware (HAL)

Os módulos robô móvel (Unidade de Controle do Robô) e visão computacional (Unidade de Processamento de Visão) formam um sistema distribuído, composto por duas unidades de processamento distintas:
- UCR (Robô Móvel): Na qual a BitDogLab (Pi Pico W), controlará o "baixo nível" do robô: controle dos motores; sensores (cores, obstáculos); gestão de energia; interface com usuário; entre outras. Tudo isso independentemente do módulo opcional de visão computacional, conforme Figura 10.
- UPV (Visão Computacional): Na qual um sistema microcontrolado (ESP32-CAM) ou um computador de placa única (Pi Zero 2 W) expandirá as capacidades da UCR como um processador de aplicação de alta performance, responsável pela visão computacional, capaz de identificar várias cores de faixas e obstáculos, enviando essas informações para o UCR executar o controle do sistema, conforme Figura 11.

Ambas as unidades (UCR e UPV) se comunicam por meio de BLE

5
. Além
disso, o robô móvel pode ainda ser controlado por um aplicativo (app), também por meio de BLE.

5 BLE: Bluetooth Low Energy, tecnologia de comunicação sem fio projetada para transferir dados de forma eficiente com baixo consumo de energia.

Sendo assim, o plano HAL define interfaces para ambas as unidades de processamento e o protocolo que as une, bem como para o app. Contudo, o desenvolvimento do app não é escopo deste projeto.

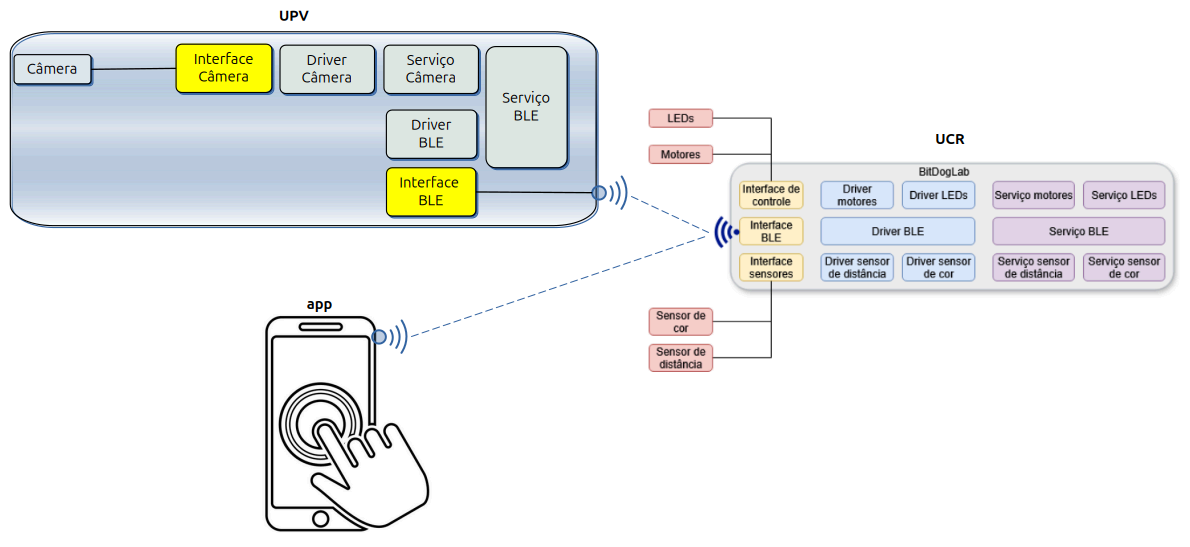
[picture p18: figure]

Figura 12 – Diagrama de camadas do Sistema de Visão. Fonte: Produzido pelos Autores.

### 4.3.1 Visão geral do sistema

O sistema será desacoplado, sendo:

- UCR (Pi Pico W): Executa a Figura 10, controlando motores, lendo sensores de proximidade/cor e obedecendo a comandos;
- UPV (Pi Zero e/ou ESP32-CAM): Executa o Figura 11, capturando imagens, executa a lógica de IA ("Seguir Faixa", "Obstáculos") e enviando comandos para a UCR executá-los;
- APP: Comando manual do robô por meio de aplicativo.

### 4.3.2 Definição do Protocolo de Comunicação (IPC

6
)

A comunicação entre a UCR e a UPV é a espinha dorsal deste design, e será implementada por meio do uso de Bluetooth/UART

7

O módulo comunicação, conforme a Figura 10, na UCR será o hal_ipc.

Já o protocolo será baseado em pacotes (CMD/Response)

8
:
[START_BYTE (0xFE)] [LENGTH] [COMMAND_ID] [PAYLOAD...] [CHECKSUM].

4.3.2.1 Plano de HAL - Parte A: Robô Móvel (UCR)

Este HAL será implementado em C/C++ (Pico SDK):

- hal_motor.h: Abstrai a "Ponte H" e o "PWM Driver".
- hal_tof.h: Abstrai o "Sensor Ultrassônico" e a "Coleta de Distância" (GPIO).
- hal_surface.h: Abstrai o "Sensor de Cor" (I2C).
- hal_ipc.h: Abstrai o driver "UART" e implementa o lado escravo do protocolo IPC.

Lógica de Implementação: O main.c da UCR irá registrar um callback

9
Quando um CMD_SET_MOTOR chegar, o callback será disparado, e ele chamará hal_motor_set_speed().

9 Callback: pedaço de código executável que é passado como parâmetro para algum método, é esperado que o método execute o código do argumento em algum momento.

8 Pacotes (CMD/Response): É um protocolo baseado em pacotes com o formato "comando/resposta" (CMD/Response) é um modelo de comunicação comum usado em redes e sistemas de hardware. Ele funciona com um sistema de requisição e resposta: um cliente envia um pacote contendo um comando (CMD), e o servidor responde com um pacote que contém a resposta (Response).

7 Bluetooth/UART: UART é a tradução livre de Receptor-Transmissor Assíncrono Universal, que é um circuito ou protocolo de hardware que permite a comunicação serial (bit a bit) entre dois dispositivos. Já o Bluetooth fornece a camada de conexão sem fio.

6
IPC: Inter Process Communication, é o conjunto de mecanismos e técnicas que permite a programas e processos se comunicarem e trocarem dados entre si em um sistema microcontrolado.

4.3.2.2 Plano de HAL - Parte B: Visão Computacional (UPV)

Este HAL é o mais crítico para a portabilidade. O "Serviço Câmera" e as "Aplicações", Figura 11, serão escritos em C++ ou Python e consumirão está HAL. A implementação dos arquivos .c/.py da HAL será diferente para o Pi Zero e para o ESP32-CAM, mas os cabeçalhos (.h) serão idênticos.

- hal_camera.h: Abstrai a captura de imagem.
Implementação (Pi Zero): Usará libcamera (C++) ou picamera2 (Python).
Implementação (ESP32-CAM): Usará esp_camera (C).
- hal_ble.h: Abstrai a comunicação externa (Figura. 11). Implementação (Pi Zero): Usará BlueZ (via D-Bus ou bibliotecas Python).
Implementação (ESP32-CAM): Usará NimBLE ou Bluedroid (ESP-IDF).
- hal_rcu_link.h: Abstrai a comunicação com a UCR. Ele implementa o lado mestre do protocolo IPC sobre UART.
Implementação (Pi Zero): Usará a biblioteca serial (Python) ou termios (C) para controlar o /dev/ttyS0.
Implementação (ESP32-CAM): Usará os drivers UART (ESP-IDF).

## 4.4 Análise de Riscos

Na tabela 6 serão analisados os riscos envolvidos na substituição de componentes, com proposições de alternativas de mitigação.

Robô Móvel

Componente | Risco | Mitigação
Sensor de Distância (HC-SR04) | O sensor pode apresentar leituras imprecisas com objetos que absorvem som ou em ângulos agudos, comprometendo a detecção de obstáculos. | Se o HC-SR04 se mostrar inadequado, ele pode ser substituído por um sensor ToF (VL53L0X), que é mais preciso.
Sensor de Cor | Variações extremas de | A camada HAL pode

(TCS34725) | iluminação no ambiente
podem afetar a precisão
da | leitura | de cor,
fazendo o robô se
perder.
incluir | rotinas | de
calibração | que | a
aplicação pode invocar
no início da operação.
Isso torna o sistema
mais | resiliente | a
diferentes | ambientes.
Caso | nenhum | dos
sensores | de | cor
apresentem | boa
confiabilidade, pode-se
usar | sensores
infravermelhos | que
detectam apenas linhas
pretas.

Motores e Ponte H Desgaste mecânico ou queima da Ponte H

Os motores TT e a ponte
H são componentes de
baixo custo e facilmente
encontrados | no
mercado.

Módulo de Visão

Componente | Risco | Mitigação
Hardware (ESP32-CAM) | O baixo poder de processamento da ESP32-CAM pode levar a uma baixa taxa de quadros por segundo (FPS) e alto tempo de classificação. Isso pode fazer com que o robô reaja lentamente a curvas, obstáculos ou mudanças na faixa, comprometendo seu desempenho. | Utilizar bibliotecas e frameworks que demandam menor capacidade computacional. Priorizar modelos de IA otimizados para microcontroladores (TinyML) e algoritmos de visão clássica mais simples, focados no processamento de cores em vez de detecção complexa de objetos.
Hardware (Raspberry Pi Zero 2 W) | O Pi Zero 2 W consome significativamente mais | Incorporar um módulo regulador de tensão

energia (1500 mW) e
exige uma fonte de 5V,
incompatível com a
tensão | nativa | das
baterias de 3.7V. Isso
pode | reduzir
drasticamente | a
autonomia do robô e
exigir componentes
adicionais, aumentando
o | custo | e | a
complexidade | do
projeto.

(step-up/boost) para
elevar e estabilizar a
tensão das baterias
para 5V, como o modelo
JX-887Y | sugerido
anteriormente. | No
software, implementar
rotinas de economia de
energia, como desativar
periféricos não utilizados e ajustar a frequência do
processador
dinamicamente.
Câmera | Variações na iluminação
do ambiente (sombras,
reflexos), desfoque de
movimento devido à alta
velocidade | ou | um
ângulo de montagem
inadequado podem
degradar a qualidade
da imagem. Isso pode
levar | a | detecções
incorretas | da | faixa
colorida | ou | de
obstáculos.

Projetar um suporte para
a | câmera | que | a
posicione em um ângulo
ótimo | e | minimize
reflexos. Se necessário,
adicionar iluminação
própria com LEDs para
garantir condições de luz
consistentes.
Implementar no software
da UPV rotinas de
calibração de cor e
normalização | de
imagem que se ajustem
às | condições | do
ambiente no início da
operação.

Tabela 6 – Análise de riscos e mitigação Fonte: Produzido pelos Autores.

## 4.5 Diagrama consolidado do sistema completo

A Figura 13 apresenta o diagrama de software e camadas detalhado dos módulos robô móvel e visão computacional.

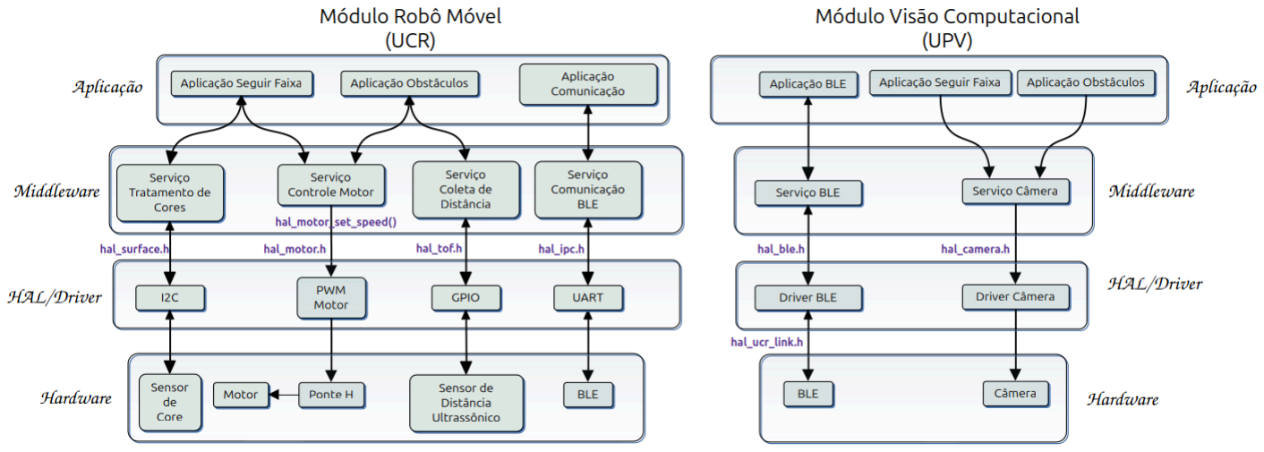
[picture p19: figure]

Figura 13 – Diagrama de camadas e software detalhado. Fonte: Produzido pelos Autores.

# 5 Referências

[1] A. Osterwalder, G. Bernarda, Y. Pigneur “Value Proposition Design: Como construir propostas de valor inovadoras”, (https://books.google.com.br/books/about/Value_Proposition_Design.html?id=7qCkDwAAQBAJ&redir_esc=y) 2019.
[2] Market Research Future (MRF), “Brazil Educational Robots Market Research Report - Forecast to 2035”, (https://www.grandviewresearch.com/horizon/outlook/educational-robot-market/brazil) 2024.
[3] M. Rovai, “Edge AI Engineering: Hands-on with the Raspberry Pi”, (https://mjrovai.github.io/EdgeML_Made_Ease_ebook/) 2025.

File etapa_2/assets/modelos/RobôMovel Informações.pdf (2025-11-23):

# Robô Móvel Skid-Steer - Informações

### Desenho com medidas do robô


### Desenhos do chassis para impressão 3D

RoboSeguidorCor (https://drive.google.com/drive/folders/11qQYzF-nzUK6vm_2F0JC38c8ogJY-rFB?usp=sharing) <- Link Google Drive ABS_1.0070_chassis_para_4x4_v4.STL ABS_dir_1.0071_suporteBitDog_MaoFrancesa_v3.STL ABS_esq_1.0071_suporteBitDog_MaoFrancesa_v3.STL As ‘mãos francesas’ são coladas com fita dupla-face no chassis

### Programa em MicroPython do robô

https://github.com/BitDogLab/BitDogLab/tree/main/softwares/RoboMovel

### Nomes dos apps Android que controlam robô

Arduino Bluetooth Controller (por Giristudio)
BT Car Controller-Arduino/ESP (por Giristudio)

### Lista de componentes

- placa BitDogLab v6 ou v7
- 4 motores tt dc 3-6V com redutor e roda de 68mm
2 motores traseiros (master) com rabichos JST-SH 2P e 4 jumpers fêmea soldados 2 motores dianteiros (slave) com 4 jumpers macho soldados
- chassis impresso em ABS v4
- 2 mãos-francesas impressas em ABS v3
- fita dupla-face
- 4 parafusos M3x25
- 4 porcas M3
- módulo ponteH tbn6612fng (módulo em PCB BitDogLab)
- cabo flat IDC 02x07
- suporte para 2 baterias 18650
- 2 baterias Li-Ion 3,7V 18650
- conector XT30 macho
- módulo bluetooth HC05

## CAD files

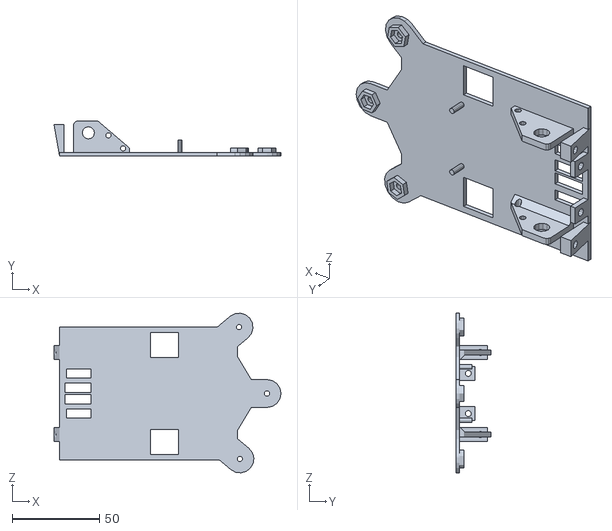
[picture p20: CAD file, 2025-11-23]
etapa_2/assets/modelos/STL/Montagem_chassis_ajuste_m3 - chassis_com_ajuste_m3-3.STL
130.0 x 20.0 x 91.5

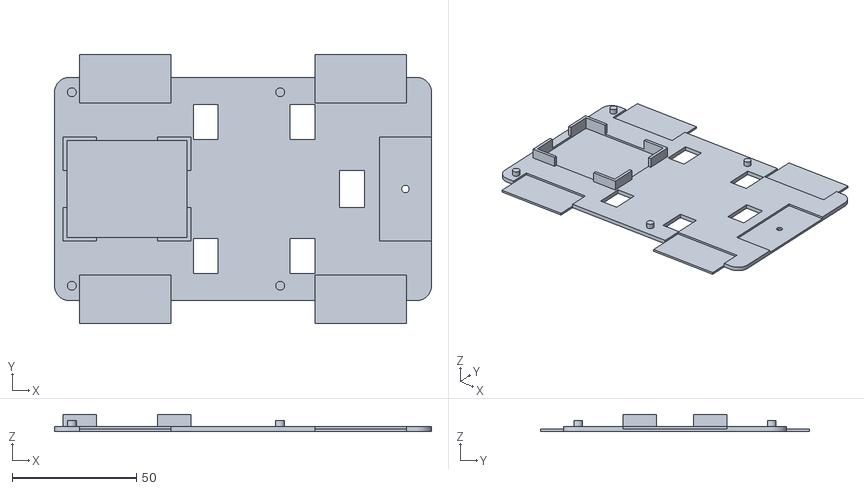
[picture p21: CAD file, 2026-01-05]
etapa_3/assets/3d_parts/Part Studio 1_Luan - chassi.stl
152.0 x 108.5 x 7.00

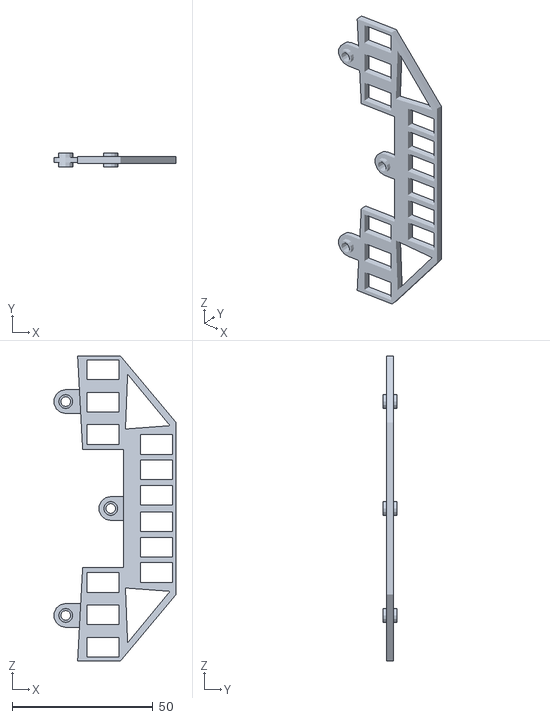
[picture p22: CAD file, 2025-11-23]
etapa_2/assets/modelos/STL/Montagem_chassis_ajuste_m3 - suporte_sensores_com_ajuste-3.STL
43.3 x 4.80 x 108.4

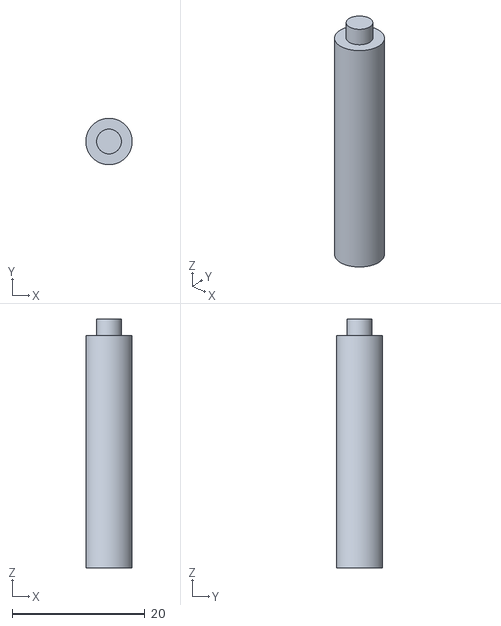
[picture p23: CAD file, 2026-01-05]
etapa_3/assets/3d_parts/Part Studio 1_Luan - pino.stl
7.00 x 7.00 x 37.5

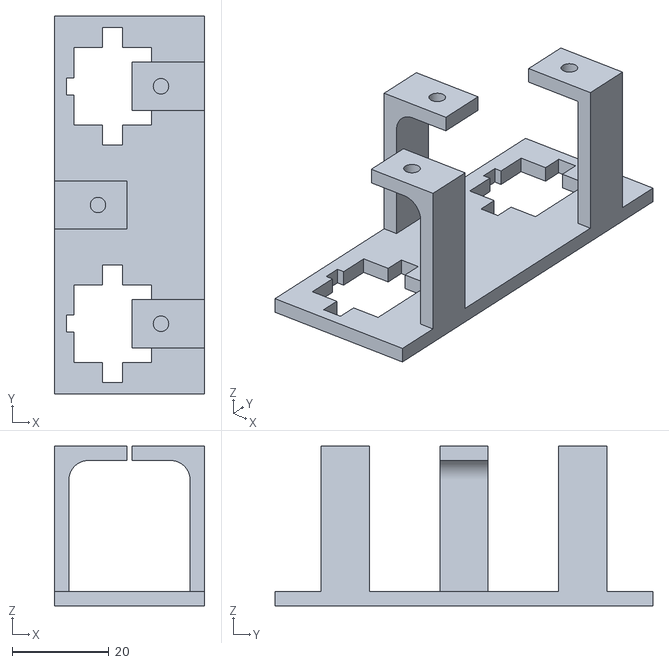
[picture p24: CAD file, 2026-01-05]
etapa_3/assets/3d_parts/suporte_sensor_cor.stl
31.0 x 78.0 x 33.0

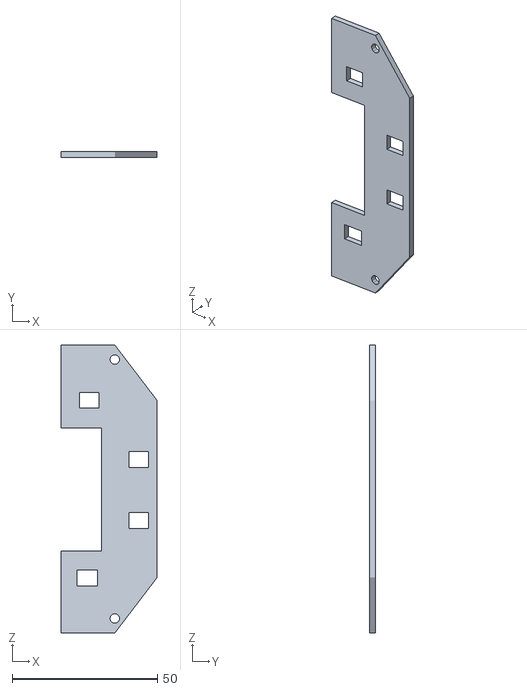
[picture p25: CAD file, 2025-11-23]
etapa_2/assets/modelos/STL/Montagem_chassis_ajuste_m3 - Placa_sensores_reflexivos-1.STL
33.0 x 2.00 x 99.0

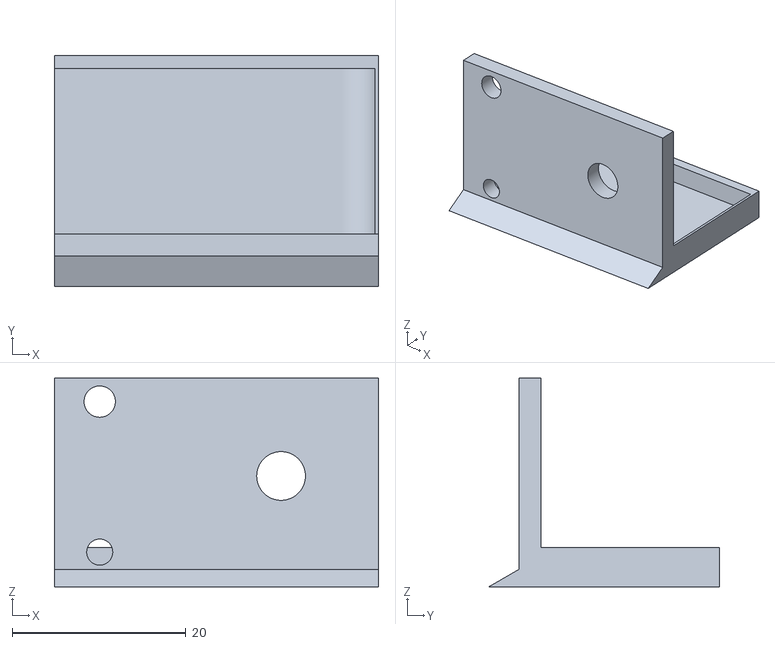
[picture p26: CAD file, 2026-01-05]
etapa_3/assets/3d_parts/Part Studio 1_Luan - suporte_motor_dir.stl
37.3 x 26.5 x 24.0

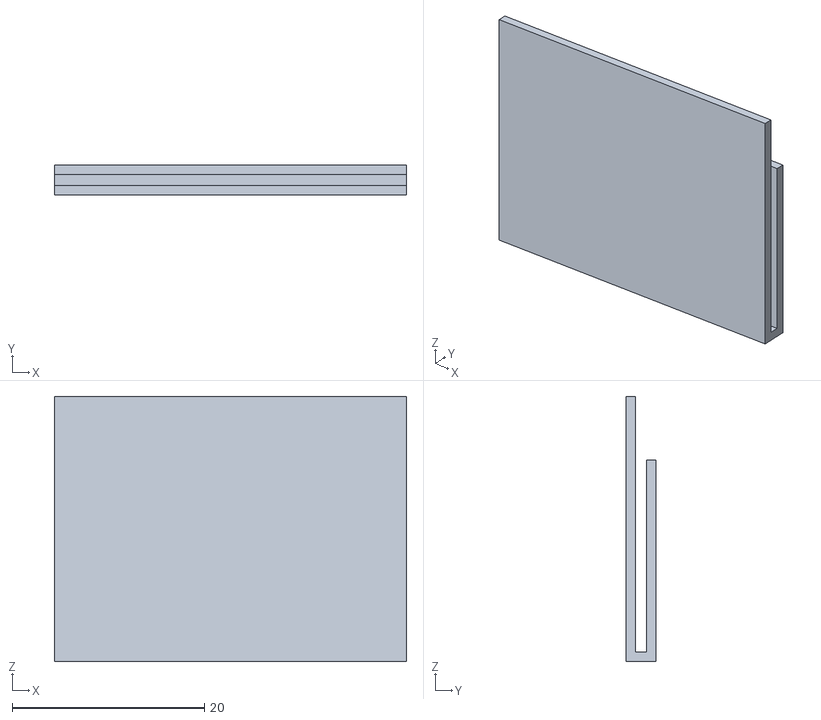
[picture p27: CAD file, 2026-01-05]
etapa_3/assets/3d_parts/Part Studio 1_Luan - encaixe_motor.stl
36.6 x 3.10 x 27.6

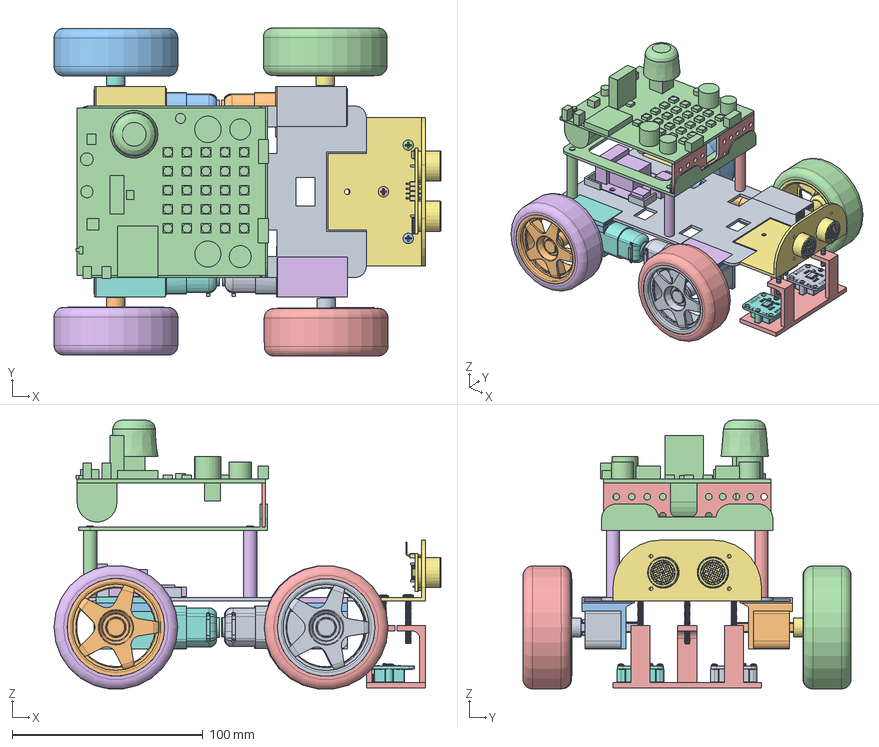
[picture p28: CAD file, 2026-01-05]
etapa_3/assets/3d_parts/robo_movel.FCStd
203.1 x 172.3 x 141.1 mm
chassi
Part Studio 1_Luan - Part 3_001
Part Studio 1_Luan - Part 4_001
Part Studio 1_Luan - Part 7_001
Part Studio 1_Luan - Part 8_001
Part Studio 1_Luan - Part 9_001
Part Studio 1_Luan - Part 9_002
Part Studio 1_Luan - Part 9_003
Part Studio 1_Luan - Part 9_004
Part Studio 1_Luan - Part 4_002
Part Studio 1_Luan - Part 3_002
Part Studio 1_Luan - Part 8_002
Part Studio 1_Luan - Part 8_003
Part Studio 1_Luan - Part 8_004
sup_dist1_001
motor_redutor - Part 2_001
motor_redutor - Part 2_002
motor_redutor - Part 2_003
motor_redutor - Part 2_004
placa_BitDogLab - Part 2_001
placa_BitDogLab - Part 3_001
Placa_MotorDriver - Part 2_001
Wheel D65x25 - Part 3_001
Wheel D65x25 - Part 3_002
Wheel D65x25 - Part 3_003
Wheel D65x25 - Part 3_004
Wheel D65x25 - Part 4_001
Wheel D65x25 - Part 4_002
Wheel D65x25 - Part 4_003
Wheel D65x25 - Part 4_004
HC-SR04 Sensor1_001
GY-33 TCS34725 Color Sensor Module1_001
GY-33 TCS34725 Color Sensor Module1_002
m3-25mm - Part 2_001
m3-25mm - Part 2_002
m3-25mm - Part 2_003
sup_cor_v4_001

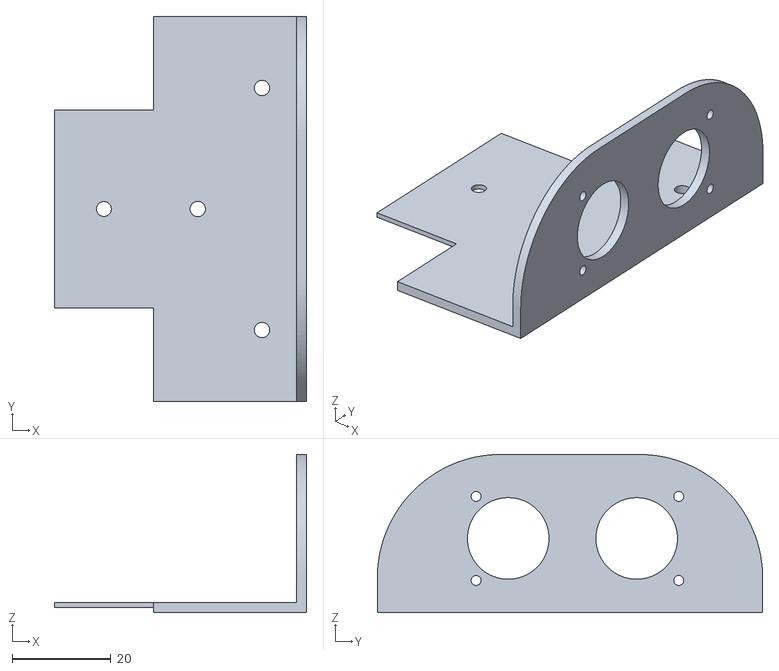
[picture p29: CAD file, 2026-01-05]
etapa_3/assets/3d_parts/suporte_sensor_dist.stl
51.0 x 78.0 x 32.0

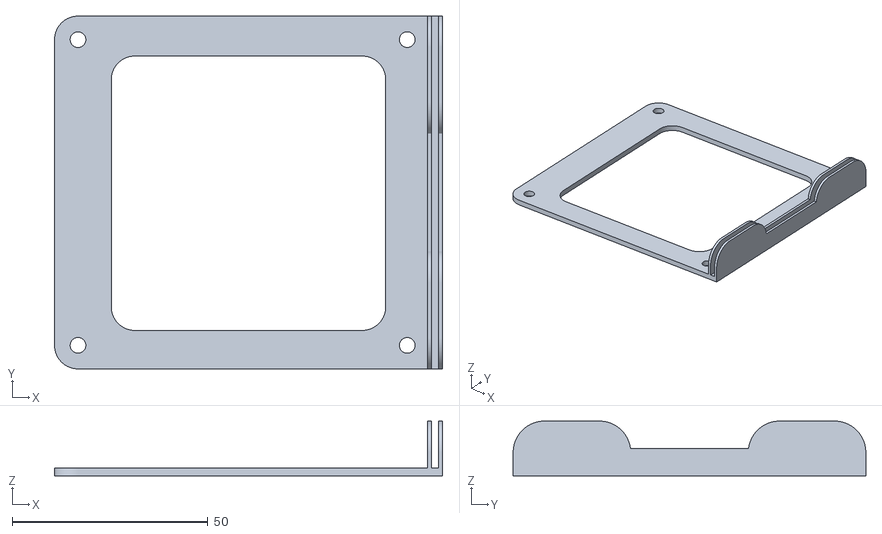
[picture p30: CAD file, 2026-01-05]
etapa_3/assets/3d_parts/Part Studio 1_Luan - suporte_bitdoglab.stl
99.0 x 90.0 x 14.0

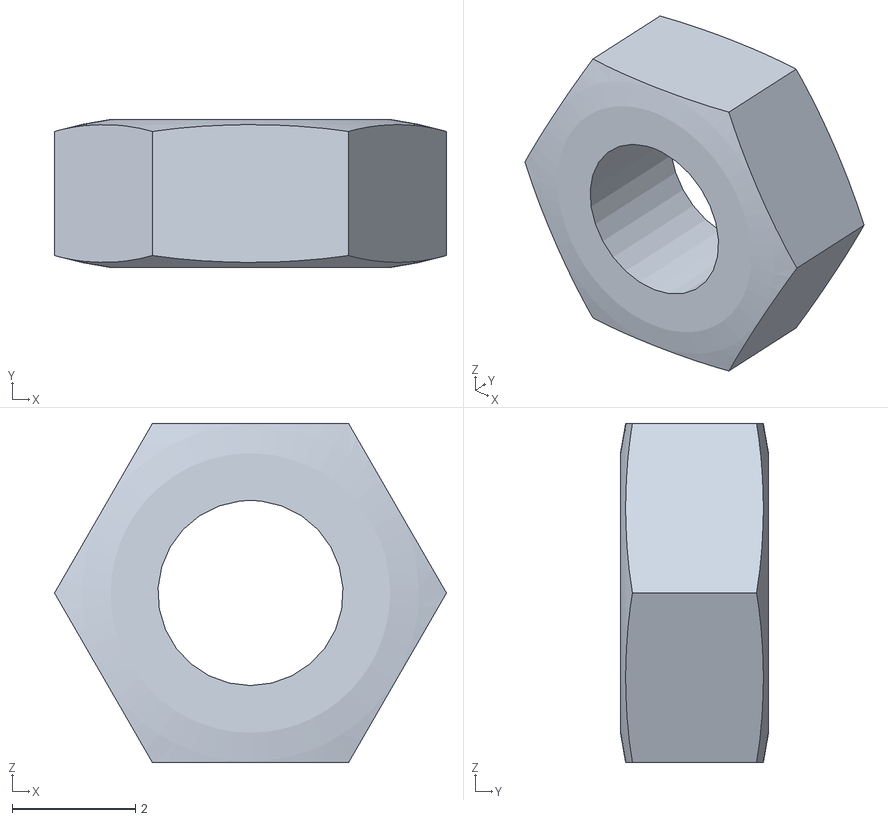
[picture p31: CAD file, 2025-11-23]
etapa_2/assets/modelos/STL/Montagem_chassis_ajuste_m3 - M3_assembly-1 M3_nut-1.STL
6.35 x 2.40 x 5.50

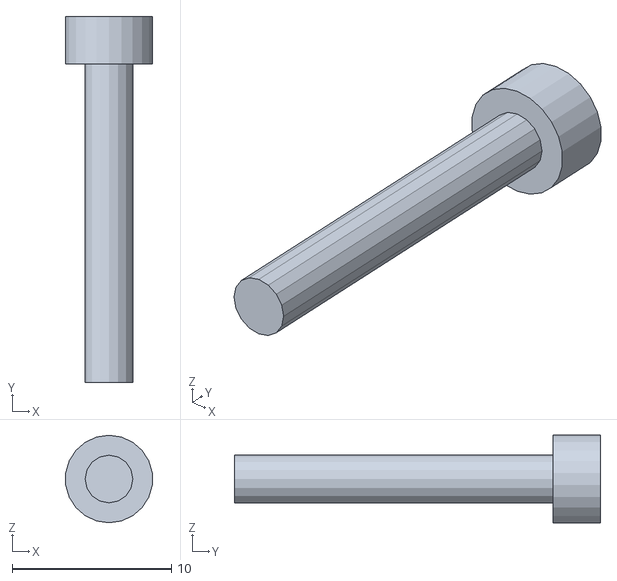
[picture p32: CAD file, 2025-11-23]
etapa_2/assets/modelos/STL/Montagem_chassis_ajuste_m3 - M3_assembly-1 M3_cap_screw-1.STL
5.44 x 23.0 x 5.50

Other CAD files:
etapa_3/assets/3d_parts/Part Studio 1_Luan - suporte_motor_esq.stl

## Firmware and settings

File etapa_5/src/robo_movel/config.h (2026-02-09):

/**
 * @file config.h
 * @brief Hardware configuration and global definitions for the color line follower robot
 *
 * This header contains all pin definitions, constants, and shared types used
 * across the application modules.
 */

#ifndef CONFIG_H
#define CONFIG_H

#include <stdint.h>
#include <stdbool.h>
#include "hardware/i2c.h"

/* ==========================================================================
 * PIN DEFINITIONS
 * ========================================================================== */

/* Onboard LED */
#define PIN_LED_ONBOARD     25

/* RGB LED Indicator */
#define PIN_LED_GREEN       11
#define PIN_LED_BLUE        12
#define PIN_LED_RED         13

/* Buttons */
#define PIN_BTN_START       5   /* Button A - Start/Stop */
#define PIN_BTN_CALIBRATE   6   /* Button B - White calibration */

/* Motor Driver (TB6612) */
#define PIN_MOTOR_L_FWD     9   /* Left motor forward */
#define PIN_MOTOR_L_BWD     4   /* Left motor backward */
#define PIN_MOTOR_L_PWM     8   /* Left motor PWM */
#define PIN_MOTOR_R_FWD     18  /* Right motor forward */
#define PIN_MOTOR_R_BWD     19  /* Right motor backward */
#define PIN_MOTOR_R_PWM     16  /* Right motor PWM */
#define PIN_MOTOR_STBY      20  /* Standby pin */

/* I2C Bus 0 - Left color sensor */
#define PIN_I2C0_SDA        0
#define PIN_I2C0_SCL        1

/* I2C Bus 1 - Right color sensor + Ultrasonic */
#define PIN_I2C1_SDA        2
#define PIN_I2C1_SCL        3

/* ==========================================================================
 * MOTOR CONFIGURATION
 * ========================================================================== */

#define DEFAULT_MOTOR_BASE_SPEED    16000   /* Base PWM value for straight movement */
#define DEFAULT_MOTOR_SPIN_SPEED    15000   /* PWM value for spin/turn maneuvers */
#define DEFAULT_MOTOR_KICK_PWM      30000   /* Maximum power for startup kick to overcome inertia */
#define DEFAULT_MOTOR_KICK_TIME_MS  60      /* Duration of startup kick (milliseconds) */
#define DEFAULT_MOTOR_TURN_TIME_MS  1000     /* Time for 90-degree turn (milliseconds) */

/* ==========================================================================
 * SENSOR CONFIGURATION
 * ========================================================================== */

/* I2C */
#define I2C_BAUDRATE        100000  /* 100kHz for SR04 compatibility */

/* TCS34725 Color Sensor */
#define TCS_I2C_ADDR        0x29
#define TCS_INTEGRATION     0xFE    /* Integration time setting (2 cycles = 4.8ms) */
#define TCS_GAIN            0x01    /* 4x gain */

/* SR04 Ultrasonic Sensor (I2C module) */
#define SR04_I2C_ADDR       0x57
#define SR04_TRIGGER_CMD    0x01

/* ==========================================================================
 * COLOR DETECTION THRESHOLDS
 * ========================================================================== */

/**
 * Black detection threshold.
 * If the "Clear" channel value is below this, the surface is considered black.
 * - Increase if robot doesn't stop on black
 * - Decrease if robot stops on colored lines
 */
#define COLOR_BLACK_THRESHOLD   40

/* Obstacle detection distance (millimeters) */
#define OBSTACLE_DISTANCE_MM    200

/* Priority lock duration (milliseconds) */
#define COLOR_LOCK_TIME_MS      500

/* ==========================================================================
 * SHARED TYPES
 * ========================================================================== */

/**
 * @brief Raw color data from TCS34725 sensor
 */
typedef struct {
    uint16_t r;     /* Red channel */
    uint16_t g;     /* Green channel */
    uint16_t b;     /* Blue channel */
    uint16_t c;     /* Clear channel (luminosity) */
    bool valid;     /* True if reading was successful */
} ColorData;

/**
 * @brief Detected color type with priority ordering
 *
 * Values are ordered by priority: higher value = higher priority
 */
typedef enum {
    COLOR_NONE   = 0,
    COLOR_BLUE   = 1,
    COLOR_RED    = 2,
    COLOR_YELLOW = 3,
    COLOR_BLACK  = 4   /* Special case: triggers stop */
} ColorType;

#endif /* CONFIG_H */

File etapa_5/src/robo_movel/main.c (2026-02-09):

/**
 * @file main.c
 * @brief Color line follower robot with BLE control
 *
 * This application implements a line-following robot that:
 * - Follows colored lines controlled via BLE
 * - Stops when detecting black
 * - Avoids obstacles using ultrasonic sensor
 *
 * BLE Commands:
 * - "start" / "stop" - Control robot running state
 * - "azul" / "vermelho" / "amarelo" / "auto" - Color mode selection
 *
 * Button A (GPIO 5): White calibration
 */

#include <stdio.h>
#include "pico/stdlib.h"
#include "pico/cyw43_arch.h"
#include "hardware/i2c.h"
#include "hardware/timer.h"

#include "config.h"
#include "led.h"
#include "motor.h"
#include "sensor.h"
#include "ble_server.h"

/* ==========================================================================
 * Global State Variables
 * ========================================================================== */

/* Current sensor readings (updated by timer callback) */
static volatile ColorType g_color_left = COLOR_NONE;
static volatile ColorType g_color_right = COLOR_NONE;
static volatile uint16_t g_distance_mm = 9999;
static volatile bool g_new_reading = false;

/* Ultrasonic sensor timing */
static volatile int g_ultrasonic_counter = 0;

/* Calibration request flag */
static volatile bool g_calibration_requested = false;
static volatile uint64_t g_last_button_time = 0;
#define BUTTON_DEBOUNCE_US 200000  /* 200ms debounce */

/* Color priority lock (prevents oscillation between colors) */
static ColorType g_locked_priority = COLOR_NONE;
static absolute_time_t g_lock_start_time;

/* ==========================================================================
 * Timer Callback - Sensor Reading (10ms interval)
 * ========================================================================== */

static bool timer_callback(struct repeating_timer *t)
{
    (void)t;

    /* Read left color sensor with moving average filter (I2C0) */
    ColorData data_left = tcs_read_filtered(i2c0, true);
    if (data_left.valid) {
        g_color_left = color_identify_calibrated(data_left, true);
    }

    /* Read right color sensor with moving average filter (I2C1) */
    ColorData data_right = tcs_read_filtered(i2c1, false);
    if (data_right.valid) {
        g_color_right = color_identify_calibrated(data_right, false);
    }

    /* Ultrasonic sensor reading (every 100ms) */
    g_ultrasonic_counter++;
    if (g_ultrasonic_counter == 1) {
        sr04_trigger(i2c1);
    } else if (g_ultrasonic_counter >= 10) {
        uint16_t distance = sr04_read(i2c1);
        if (distance != 9999) {
            g_distance_mm = distance;
        }
        g_ultrasonic_counter = 0;
    }

    g_new_reading = true;
    return true;
}

/* ==========================================================================
 * I2C Initialization
 * ========================================================================== */

static void i2c_buses_init(void)
{
    /* I2C0: Left color sensor */
    i2c_init(i2c0, I2C_BAUDRATE);
    gpio_set_function(PIN_I2C0_SDA, GPIO_FUNC_I2C);
    gpio_set_function(PIN_I2C0_SCL, GPIO_FUNC_I2C);
    gpio_pull_up(PIN_I2C0_SDA);
    gpio_pull_up(PIN_I2C0_SCL);

    /* I2C1: Right color sensor + Ultrasonic */
    i2c_init(i2c1, I2C_BAUDRATE);
    gpio_set_function(PIN_I2C1_SDA, GPIO_FUNC_I2C);
    gpio_set_function(PIN_I2C1_SCL, GPIO_FUNC_I2C);
    gpio_pull_up(PIN_I2C1_SDA);
    gpio_pull_up(PIN_I2C1_SCL);
}

/* ==========================================================================
 * Calibration Button (Button A - GPIO 5)
 * ========================================================================== */

static void calibration_button_callback(uint gpio, uint32_t events)
{
    (void)events;
    
    if (gpio == PIN_BTN_START) {
        uint64_t now = time_us_64();
        if (now - g_last_button_time > BUTTON_DEBOUNCE_US) {
            g_calibration_requested = true;
            g_last_button_time = now;
        }
    }
}

static void button_init(void)
{
    /* Button A - Calibration */
    gpio_init(PIN_BTN_START);
    gpio_set_dir(PIN_BTN_START, GPIO_IN);
    gpio_pull_up(PIN_BTN_START);
    
    /* Enable interrupt */
    gpio_set_irq_enabled_with_callback(PIN_BTN_START, 
        GPIO_IRQ_EDGE_FALL, true, calibration_button_callback);
    
    printf("Button A (GPIO%d) = White Calibration\n", PIN_BTN_START);
}

/* ==========================================================================
 * Color Mode Filtering
 * ========================================================================== */

/**
 * @brief Apply color mode filter from BLE
 */
static ColorType apply_color_mode_filter(ColorType detected, ColorMode mode)
{
    if (mode == COLOR_MODE_AUTO) {
        return detected;  /* No filtering in auto mode */
    }
    
    /* In specific mode, only pass the selected color */
    switch (mode) {
        case COLOR_MODE_BLUE:
            return (detected == COLOR_BLUE) ? COLOR_BLUE : COLOR_NONE;
        case COLOR_MODE_RED:
            return (detected == COLOR_RED) ? COLOR_RED : COLOR_NONE;
        case COLOR_MODE_YELLOW:
            return (detected == COLOR_YELLOW) ? COLOR_YELLOW : COLOR_NONE;
        default:
            return detected;
    }
}

/**
 * @brief Apply priority filter (for auto mode)
 */
static ColorType apply_priority_filter(ColorType detected, bool lock_active, ColorType locked)
{
    if (detected == COLOR_YELLOW) {
        return COLOR_YELLOW;
    }
    if (detected == COLOR_RED && (!lock_active || locked <= COLOR_RED)) {
        return COLOR_RED;
    }
    if (detected == COLOR_BLUE && (!lock_active || locked <= COLOR_BLUE)) {
        return COLOR_BLUE;
    }
    return COLOR_NONE;
}

/* ==========================================================================
 * Main Application
 * ========================================================================== */

int main(void)
{
    /* Initialize stdio for debug output */
    stdio_init_all();
    
    printf("\n=== RoboMovel BLE Line Follower ===\n");

    /* Initialize CYW43 (WiFi/BT chip) */
    if (cyw43_arch_init()) {
        printf("ERROR: Failed to initialize CYW43\n");
        return -1;
    }
    printf("CYW43 initialized\n");

    /* Initialize hardware modules */
    leds_init();
    button_init();
    i2c_buses_init();
    motors_init();

    /* Initialize sensors */
    tcs_init(i2c0);
    tcs_init(i2c1);

    /* Initialize BLE server */
    ble_server_init();

    /* Start sensor reading timer (5ms interval) */
    struct repeating_timer timer;
    add_repeating_timer_ms(5, timer_callback, NULL, &timer);

    printf("Commands via BLE: start, stop, azul, vermelho, amarelo, auto\n");
    printf("Button A: White calibration\n");
    printf("Ready!\n");

    /* Get robot state from BLE module */
    RobotState* robot = ble_get_robot_state();

    /* ---------- Main Loop ---------- */
    while (true) {
        
        /* ----- Handle Calibration Request ----- */
        /* Polling fallback for button */
        if (!gpio_get(PIN_BTN_START)) {
            uint64_t now = time_us_64();
            if (now - g_last_button_time > BUTTON_DEBOUNCE_US) {
                g_calibration_requested = true;
                g_last_button_time = now;
            }
        }
        
        if (g_calibration_requested) {
            g_calibration_requested = false;
            
            /* Visual feedback */
            leds_set(false, true, false); /* Blue */
            
            /* Calibrate both sensors */
            tcs_calibrate_white(i2c0, true);
            tcs_calibrate_white(i2c1, false);
            robot->calibrated = true;
            
            printf(">>> WHITE CALIBRATION COMPLETE <<<\n");
            ble_update_status("Calibrado");
            
            /* Flash green 3 times */
            for (int i = 0; i < 3; i++) {
                leds_set(false, true, false);
                sleep_ms(200);
                leds_set(false, false, false);
                sleep_ms(200);
            }
        }

        /* ----- Standby Mode (from BLE) ----- */
        if (!robot->running) {
            motors_stop();
            leds_set(true, true, true); /* White = waiting */
            sleep_ms(50);
            continue;
        }
        
        /* Sync Motor Parameters from BLE */
        motors_set_params(
            robot->motor_base_speed,
            robot->motor_spin_speed,
            robot->motor_kick_pwm,
            robot->motor_kick_time_ms,
            robot->motor_turn_time_ms
        );

        /* Wait for new sensor reading */
        if (!g_new_reading) {
            sleep_ms(1);
            continue;
        }
        g_new_reading = false;

        /* Get current readings */
        uint16_t distance = g_distance_mm;
        ColorType color_left = g_color_left;
        ColorType color_right = g_color_right;

        /* ----- Black Detection: Emergency Stop ----- */
        if (color_left == COLOR_BLACK || color_right == COLOR_BLACK) {
            printf(">>> BLACK DETECTED - STOPPING <<<\n");
            motors_stop();
            leds_set(true, false, true); /* Magenta */
            robot->running = false;
            ble_update_status("Parou: Preto");
            sleep_ms(2000);
            continue;
        }

        /* ----- Obstacle Detection ----- */
        if (distance < OBSTACLE_DISTANCE_MM) {
            leds_set(false, false, true); /* Red */
            motors_spin_obstacle();
            continue;
        }

        /* ----- Apply Color Mode Filter (from BLE) ----- */
        ColorType filtered_left = apply_color_mode_filter(color_left, robot->color_mode);
        ColorType filtered_right = apply_color_mode_filter(color_right, robot->color_mode);

        /* ----- Color Priority Logic (for auto mode) ----- */
        ColorType best_left, best_right;
        
        if (robot->color_mode == COLOR_MODE_AUTO) {
            /* Check if priority lock is still active */
            bool lock_active = false;
            if (g_locked_priority != COLOR_NONE) {
                int64_t elapsed_us = absolute_time_diff_us(g_lock_start_time, get_absolute_time());
                if (elapsed_us < (COLOR_LOCK_TIME_MS * 1000)) {
                    lock_active = true;
                } else {
                    g_locked_priority = COLOR_NONE;
                }
            }

            best_left = apply_priority_filter(filtered_left, lock_active, g_locked_priority);
            best_right = apply_priority_filter(filtered_right, lock_active, g_locked_priority);

            /* Update lock */
            ColorType highest = (best_left > best_right) ? best_left : best_right;
            if (highest > g_locked_priority) {
                g_locked_priority = highest;
                g_lock_start_time = get_absolute_time();
            }
        } else {
            /* In specific color mode, just use filtered values */
            best_left = filtered_left;
            best_right = filtered_right;
        }

        /* ----- Movement Decision ----- */
        if (best_left > best_right) {
            leds_set(false, true, false); /* Green */
            motors_spin_left();
        } else if (best_right > best_left) {
            leds_set(false, true, false); /* Green */
            motors_spin_right();
        } else {
            leds_set(false, false, false); /* Off */
            motors_forward();
        }

        sleep_ms(1);
    }

    return 0;
}

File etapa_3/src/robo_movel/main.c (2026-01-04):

/**
 * @file main.c
 * @brief Color line follower robot - Main application
 *
 * This application implements a line-following robot that:
 * - Follows colored lines with priority: Yellow > Red > Blue
 * - Stops when detecting black
 * - Avoids obstacles using ultrasonic sensor
 *
 * Hardware:
 * - Raspberry Pi Pico
 * - 2x TCS34725 color sensors (left/right)
 * - 1x SR04 ultrasonic sensor (I2C module)
 * - TB6612 motor driver with 2x DC motors
 * - RGB LED for status indication
 */

#include <stdio.h>
#include "pico/stdlib.h"
#include "hardware/i2c.h"
#include "hardware/timer.h"

#include "config.h"
#include "led.h"
#include "motor.h"
#include "sensor.h"

/* ==========================================================================
 * Global State Variables
 * ========================================================================== */

/* Current sensor readings (updated by timer callback) */
static volatile ColorType g_color_left = COLOR_NONE;
static volatile ColorType g_color_right = COLOR_NONE;
static volatile uint16_t g_distance_mm = 9999;
static volatile bool g_new_reading = false;

/* Ultrasonic sensor timing */
static volatile int g_ultrasonic_counter = 0;

/* Application mode */
static volatile bool g_standby_mode = true;

/* Button interrupt debounce */
static volatile uint64_t g_last_button_time = 0;
#define BUTTON_DEBOUNCE_US 200000  /* 200ms debounce */

/* Color priority lock (prevents oscillation between colors) */
static ColorType g_locked_priority = COLOR_NONE;
static absolute_time_t g_lock_start_time;

/* ==========================================================================
 * Timer Callback - Sensor Reading (10ms interval)
 * ========================================================================== */

static bool timer_callback(struct repeating_timer *t)
{
    (void)t; /* Unused parameter */

    /* Read left color sensor with moving average filter (I2C0) */
    ColorData data_left = tcs_read_filtered(i2c0, true);
    if (data_left.valid) {
        g_color_left = color_identify(data_left);
    }

    /* Read right color sensor with moving average filter (I2C1) */
    ColorData data_right = tcs_read_filtered(i2c1, false);
    if (data_right.valid) {
        g_color_right = color_identify(data_right);
    }

    /* Ultrasonic sensor reading (every 100ms) */
    g_ultrasonic_counter++;
    if (g_ultrasonic_counter == 1) {
        sr04_trigger(i2c1);
    } else if (g_ultrasonic_counter >= 10) {
        uint16_t distance = sr04_read(i2c1);
        if (distance != 9999) {
            g_distance_mm = distance;
        }
        g_ultrasonic_counter = 0;
    }

    g_new_reading = true;
    return true;
}

/* ==========================================================================
 * I2C Initialization
 * ========================================================================== */

static void i2c_buses_init(void)
{
    /* I2C0: Left color sensor */
    i2c_init(i2c0, I2C_BAUDRATE);
    gpio_set_function(PIN_I2C0_SDA, GPIO_FUNC_I2C);
    gpio_set_function(PIN_I2C0_SCL, GPIO_FUNC_I2C);
    gpio_pull_up(PIN_I2C0_SDA);
    gpio_pull_up(PIN_I2C0_SCL);

    /* I2C1: Right color sensor + Ultrasonic */
    i2c_init(i2c1, I2C_BAUDRATE);
    gpio_set_function(PIN_I2C1_SDA, GPIO_FUNC_I2C);
    gpio_set_function(PIN_I2C1_SCL, GPIO_FUNC_I2C);
    gpio_pull_up(PIN_I2C1_SDA);
    gpio_pull_up(PIN_I2C1_SCL);
}

/* ==========================================================================
 * Button GPIO Interrupt Callback
 * ========================================================================== */

/**
 * @brief GPIO interrupt callback for button with debounce
 */
static void button_callback(uint gpio, uint32_t events)
{
    (void)events;
    
    if (gpio == PIN_BTN_START) {
        uint64_t now = time_us_64();
        if (now - g_last_button_time > BUTTON_DEBOUNCE_US) {
            g_standby_mode = !g_standby_mode;  /* Toggle mode */
            g_last_button_time = now;
        }
    }
}

/* ==========================================================================
 * Button Initialization with Interrupt
 * ========================================================================== */

static void button_init(void)
{
    gpio_init(PIN_BTN_START);
    gpio_set_dir(PIN_BTN_START, GPIO_IN);
    gpio_pull_up(PIN_BTN_START);
    
    /* Enable interrupt on falling edge with debounce callback */
    gpio_set_irq_enabled_with_callback(PIN_BTN_START, 
        GPIO_IRQ_EDGE_FALL, true, button_callback);
}

/* ==========================================================================
 * Color Priority Logic
 * ========================================================================== */

/**
 * @brief Determine the best color considering priority lock
 *
 * @param detected  The currently detected color
 * @param lock_active  Whether a priority lock is active
 * @param locked  The currently locked priority
 * @return The color to act upon (may be COLOR_NONE if blocked)
 */
static ColorType apply_priority_filter(ColorType detected, bool lock_active, ColorType locked)
{
    /* Yellow always passes (highest priority) */
    if (detected == COLOR_YELLOW) {
        return COLOR_YELLOW;
    }

    /* Red passes if not blocked by higher priority */
    if (detected == COLOR_RED && (!lock_active || locked <= COLOR_RED)) {
        return COLOR_RED;
    }

    /* Blue passes if not blocked by higher priority */
    if (detected == COLOR_BLUE && (!lock_active || locked <= COLOR_BLUE)) {
        return COLOR_BLUE;
    }

    return COLOR_NONE;
}

/* ==========================================================================
 * Main Application
 * ========================================================================== */
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

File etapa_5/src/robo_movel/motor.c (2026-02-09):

/**
 * @file motor.c
 * @brief Motor control implementation using PWM
 */

#include "motor.h"
#include "config.h"
#include "pico/stdlib.h"
#include "hardware/pwm.h"

/* --------------------------------------------------------------------------
 * State Tracking
 * -------------------------------------------------------------------------- */

typedef enum {
    MOTOR_STATE_STOP,
    MOTOR_STATE_FORWARD,
    MOTOR_STATE_LEFT,
    MOTOR_STATE_RIGHT
} MotorState;

static MotorState current_state = MOTOR_STATE_STOP;

/* --------------------------------------------------------------------------
 * Configuration Variables
 * -------------------------------------------------------------------------- */

static uint16_t g_motor_base_speed = DEFAULT_MOTOR_BASE_SPEED;
static uint16_t g_motor_spin_speed = DEFAULT_MOTOR_SPIN_SPEED;
static uint16_t g_motor_kick_pwm = DEFAULT_MOTOR_KICK_PWM;
static uint16_t g_motor_kick_time_ms = DEFAULT_MOTOR_KICK_TIME_MS;
static uint16_t g_motor_turn_time_ms = DEFAULT_MOTOR_TURN_TIME_MS;

/* --------------------------------------------------------------------------
 * Private Helper Functions
 * -------------------------------------------------------------------------- */

/**
 * @brief Configure a GPIO pin for PWM output
 */
static void pwm_pin_init(uint pin)
{
    gpio_set_function(pin, GPIO_FUNC_PWM);
    uint slice = pwm_gpio_to_slice_num(pin);
    pwm_set_wrap(slice, 65535);
    pwm_set_enabled(slice, true);
}

/* --------------------------------------------------------------------------
 * Public API
 * -------------------------------------------------------------------------- */

void motors_init(void)
{
    /* Initialize direction pins */
    gpio_init(PIN_MOTOR_L_FWD);
    gpio_set_dir(PIN_MOTOR_L_FWD, GPIO_OUT);

    gpio_init(PIN_MOTOR_L_BWD);
    gpio_set_dir(PIN_MOTOR_L_BWD, GPIO_OUT);

    gpio_init(PIN_MOTOR_R_FWD);
    gpio_set_dir(PIN_MOTOR_R_FWD, GPIO_OUT);

    gpio_init(PIN_MOTOR_R_BWD);
    gpio_set_dir(PIN_MOTOR_R_BWD, GPIO_OUT);

    /* Initialize standby pin (active high to enable driver) */
    gpio_init(PIN_MOTOR_STBY);
    gpio_set_dir(PIN_MOTOR_STBY, GPIO_OUT);
    gpio_put(PIN_MOTOR_STBY, 1);

    /* Initialize PWM pins */
    pwm_pin_init(PIN_MOTOR_L_PWM);
    pwm_pin_init(PIN_MOTOR_R_PWM);

    current_state = MOTOR_STATE_STOP;
}

void motors_set_params(uint16_t base_speed, uint16_t spin_speed, 
                       uint16_t kick_pwm, uint16_t kick_time_ms, 
                       uint16_t turn_time_ms)
{
    g_motor_base_speed = base_speed;
    g_motor_spin_speed = spin_speed;
    g_motor_kick_pwm = kick_pwm;
    g_motor_kick_time_ms = kick_time_ms;
    g_motor_turn_time_ms = turn_time_ms;
}

void motors_stop(void)
{
    gpio_put(PIN_MOTOR_L_FWD, 0);
    gpio_put(PIN_MOTOR_L_BWD, 0);
    gpio_put(PIN_MOTOR_R_FWD, 0);
    gpio_put(PIN_MOTOR_R_BWD, 0);

    pwm_set_gpio_level(PIN_MOTOR_L_PWM, 0);
    pwm_set_gpio_level(PIN_MOTOR_R_PWM, 0);

    current_state = MOTOR_STATE_STOP;
}

void motors_forward(void)
{
    gpio_put(PIN_MOTOR_L_FWD, 1);
    gpio_put(PIN_MOTOR_L_BWD, 0);
    gpio_put(PIN_MOTOR_R_FWD, 1);
    gpio_put(PIN_MOTOR_R_BWD, 0);

    if (current_state != MOTOR_STATE_FORWARD) {
        pwm_set_gpio_level(PIN_MOTOR_L_PWM, g_motor_kick_pwm);
        pwm_set_gpio_level(PIN_MOTOR_R_PWM, g_motor_kick_pwm);
        sleep_ms(g_motor_kick_time_ms);
    }

    pwm_set_gpio_level(PIN_MOTOR_L_PWM, g_motor_base_speed);
    pwm_set_gpio_level(PIN_MOTOR_R_PWM, g_motor_base_speed);
    
    current_state = MOTOR_STATE_FORWARD;
}

void motors_spin_left(void)
{
    gpio_put(PIN_MOTOR_L_FWD, 0);
    gpio_put(PIN_MOTOR_L_BWD, 1);
    gpio_put(PIN_MOTOR_R_FWD, 1);
    gpio_put(PIN_MOTOR_R_BWD, 0);

    if (current_state != MOTOR_STATE_LEFT) {
        pwm_set_gpio_level(PIN_MOTOR_L_PWM, g_motor_kick_pwm);
        pwm_set_gpio_level(PIN_MOTOR_R_PWM, g_motor_kick_pwm);
        sleep_ms(g_motor_kick_time_ms);
    }

    pwm_set_gpio_level(PIN_MOTOR_L_PWM, g_motor_base_speed);
    pwm_set_gpio_level(PIN_MOTOR_R_PWM, g_motor_spin_speed);

    current_state = MOTOR_STATE_LEFT;
}

void motors_spin_right(void)
{
    gpio_put(PIN_MOTOR_L_FWD, 1);
    gpio_put(PIN_MOTOR_L_BWD, 0);
    gpio_put(PIN_MOTOR_R_FWD, 0);
    gpio_put(PIN_MOTOR_R_BWD, 1);

    if (current_state != MOTOR_STATE_RIGHT) {
        pwm_set_gpio_level(PIN_MOTOR_L_PWM, g_motor_kick_pwm);
        pwm_set_gpio_level(PIN_MOTOR_R_PWM, g_motor_kick_pwm);
        sleep_ms(g_motor_kick_time_ms);
    }

    pwm_set_gpio_level(PIN_MOTOR_L_PWM, g_motor_base_speed);
    pwm_set_gpio_level(PIN_MOTOR_R_PWM, g_motor_spin_speed);

    current_state = MOTOR_STATE_RIGHT;
}

void motors_spin_obstacle(void)
{
    /* Spin in place: both motors at same speed, opposite directions */
    gpio_put(PIN_MOTOR_L_FWD, 1);
    gpio_put(PIN_MOTOR_L_BWD, 0);
    gpio_put(PIN_MOTOR_R_FWD, 0);
    gpio_put(PIN_MOTOR_R_BWD, 1);

    /* Apply kick since this is usually a start from stop or sudden change */
    pwm_set_gpio_level(PIN_MOTOR_L_PWM, g_motor_kick_pwm);
    pwm_set_gpio_level(PIN_MOTOR_R_PWM, g_motor_kick_pwm);
    sleep_ms(g_motor_kick_time_ms);

    pwm_set_gpio_level(PIN_MOTOR_L_PWM, g_motor_spin_speed);
    pwm_set_gpio_level(PIN_MOTOR_R_PWM, g_motor_spin_speed);
    
    current_state = MOTOR_STATE_RIGHT; /* Same as spin right */

    sleep_ms(g_motor_turn_time_ms);
}

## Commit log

2025-11-09 sensor ultrassom
2025-11-22 Notebook com Abordagem Classica de Visão Computacional
2025-11-23 Acrescentado modelos 3D impressão
    [Montagem_chassis_ajuste_m3 - M3_assembly-1 M3_cap_screw-1.STL, Montagem_chassis_ajuste_m3 - M3_assembly-1 M3_nut-1.STL, Montagem_chassis_ajuste_m3 - Placa_sens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]
2025-11-24 adição do código do carrinho seguidor de cor
2025-12-13 Acrescentado comentário do forums.raspberrypi
2025-12-13 Acrescentado nova versao do GATT Server com comandos do led RGD e matriz de de leds da ButDogLab V6 em função da cor/comandos recebidos
2025-12-14 Ajustado notificação para os clientes
2025-12-23 Cliente para a Pi Zero com comandos de direção
2025-12-27 Atualizado cliente para a Pi Zero com comandos de direção
2025-12-30 Acrescentado módulo de streamer (debug)
2025-12-31 Ajustado problema de inversão de cores Azul/Vermelho)
    [vision.py]
2026-01-02 Ajustado calibração das cores e linhas de referência e ROI
2026-01-05 adição dos modelos 3d
    [Part Studio 1_Luan - chassi.stl, Part Studio 1_Luan - encaixe_motor.stl, Part Studio 1_Luan - pino.stl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]
